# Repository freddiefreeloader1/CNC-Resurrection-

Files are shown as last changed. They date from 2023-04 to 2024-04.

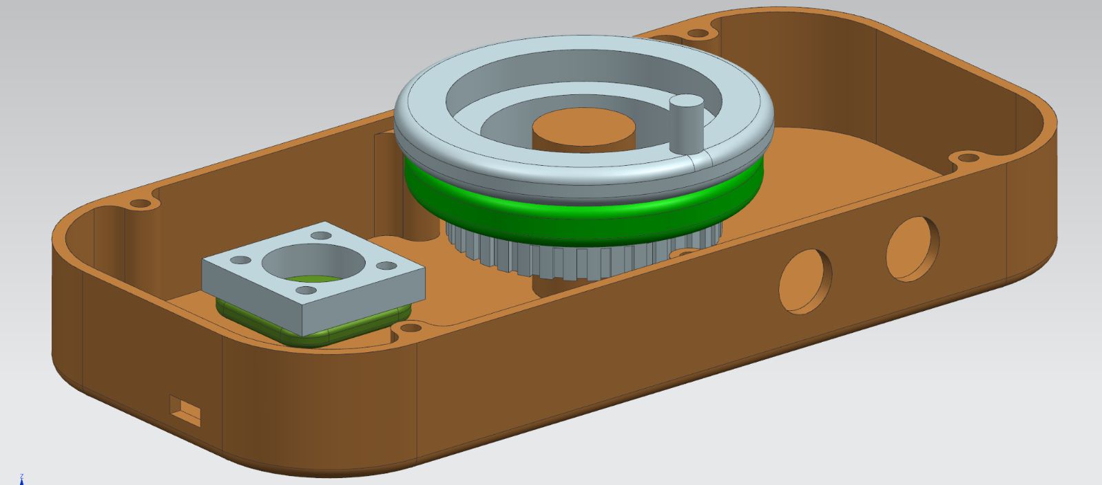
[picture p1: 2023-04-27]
img/RemoteHandWheel_Technical_Drawings/Assembly_3.jpeg

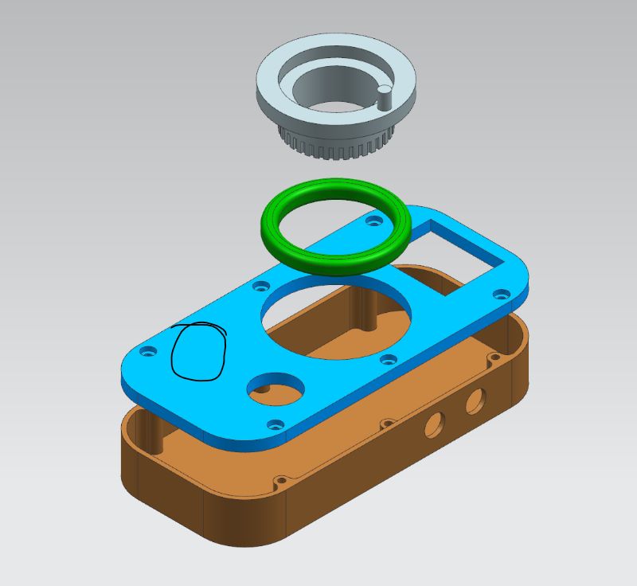
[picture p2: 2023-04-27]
img/RemoteHandWheel_Technical_Drawings/Assembly_2.jpeg

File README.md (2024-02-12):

# CNC-Resurrection
ME462 Term Project 

Main goals:
- Create a generic controller for the out of order CNC machines
- Come up with a ROS2 based universal remote handwheel/controller, mainly for the CNC's, but it should be applicable for other uses as well

Stepper Pairs:
-Pins BH and Pins DF

CNC Milling Machine Specs:

Pitch of the lead screws : 1mm

UGS Parameters:

Step size of axes : 800pulse/mm (Quarter microstepping is enabled)
Max Travel Rate : 150
Do not increase feed rate more than 100mm/min. It staggers motors because motors cannot catch that pulse speed.

REMOTE CONTROLLER DOCUMENTATION:



The Remote Controller project is an innovative and versatile solution designed to provide enhanced control and convenience for various applications. With a range of functional features, this project offers a seamless remote control experience for different devices and systems.

The centerpiece of the Remote Controller project is the GC9A01 round LCD display, which serves as the primary interface. This high-resolution display showcases a user-friendly menu system and subfunctions, allowing users to navigate through different options and select desired actions with ease.

The project currently supports two main subfunctions: CNC and CNC precision. However, the system is highly configurable, enabling the addition of more functions based on individual requirements. This flexibility ensures that the Remote Controller can be adapted to various use cases and applications.

The hardware components of the Remote Controller include a joystick, knob, and three buttons. These components are programmable, allowing users to assign specific functions to perform desired actions. The joystick provides directional control, while the knob allows for precise adjustments. The buttons offer additional input options for quick and convenient operations.

To facilitate seamless communication and integration, all data generated by the joystick, knob, and buttons are transmitted through a socket connection. This connection allows the Remote Controller to interface with other devices or systems, enabling remote control capabilities.

The data received through the socket connection is then sent via a socket-to-ROS2 bridge to a ROS2 (Robot Operating System 2) node. ROS2 provides a robust and flexible framework for managing the control and communication of robotic systems. The Remote Controller project leverages ROS2 to enable efficient data transfer, control, and coordination with other ROS2-enabled devices and modules.

For CNC operations, the Remote Controller project supports GRBL with Arduino. The data received through the socket connection is further forwarded to an Arduino board via serial communication, which interfaces with the GRBL software. This setup allows for precise control over three-axis stepper motors using the knob and joystick inputs, making it an ideal solution for CNC applications.

Powering the Remote Controller is a rechargeable 3.7V battery, providing a portable and convenient power source. The battery can be easily recharged using a micro USB connection through a charge module, ensuring uninterrupted operation. Additionally, a slider switch is incorporated, allowing users to power the controller on and off with ease, preserving battery life when not in use.

The GC9A01 round LCD display provides essential information, including the battery percentage and the position of the knob. This real-time feedback ensures users are aware of the remaining battery power and provides visual cues during operations.

The Remote Controller project offers a comprehensive solution for remote control applications. With its versatile interface, programmable components, seamless integration with ROS2, and support for CNC operations, this project enhances control and convenience across a wide range of devices and systems, providing an exceptional remote control experience.

How To Configure The Remote Controller:

1- There is an opening at the side of the controller that you can connect the Pi Pico W to PC and configure the main.py

2- In main.py, to configure the menu, you can change functions named other2, other3 to suit your needs. You can change the format of the messages sent there. 

3- You also need the to configure the ros2 node. Currently the publisher_member_function only supports the CNC applications. To change it, you need to delete all the code that has serial send in it. You should write your own parsing code for the customized messages you have written in step 2.

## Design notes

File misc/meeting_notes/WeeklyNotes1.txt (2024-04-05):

For the remote:
Joystick - 3 or 4 axis
Wireless Communication
LCD Display
Handwheel - Rotary Encoder Assembly
Functional Buttons

Wireless Communication Concern: Latencies may hinder accurate and precise movement.

CNC pulse generator - handwheel

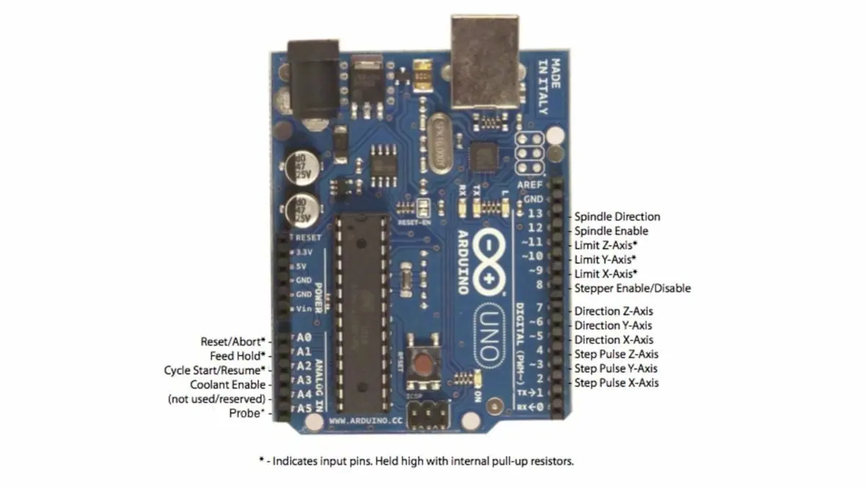
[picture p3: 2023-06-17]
misc/uno-grbl-pinout.webp

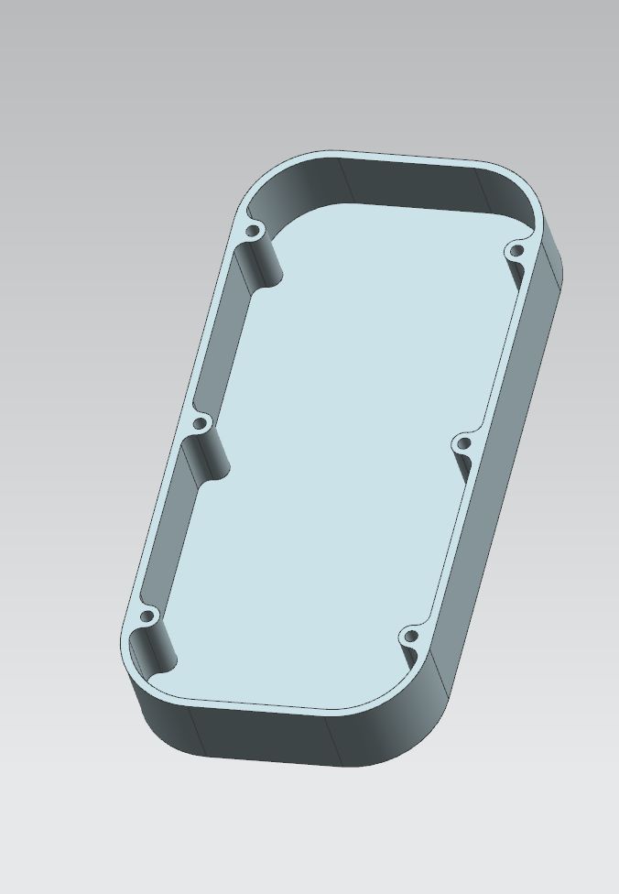
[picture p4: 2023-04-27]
img/RemoteHandWheel_Technical_Drawings/Casing.jpeg

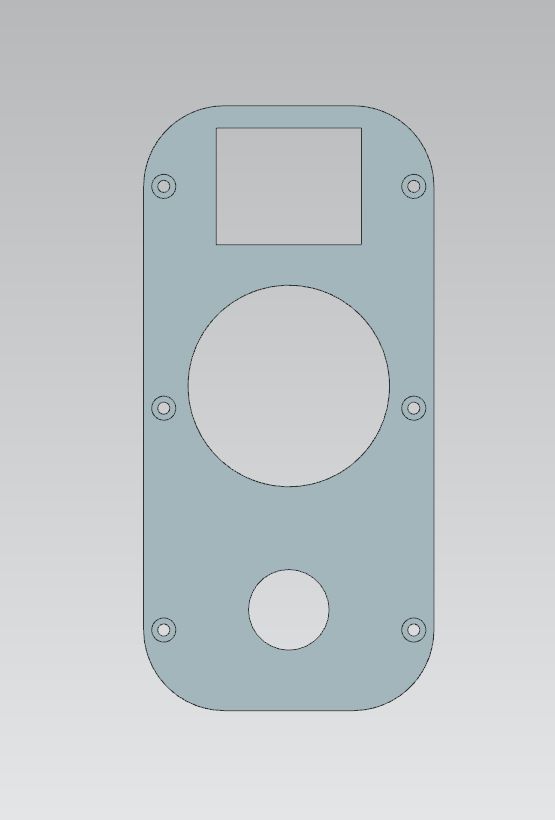
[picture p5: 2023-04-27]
img/RemoteHandWheel_Technical_Drawings/Frame_1.jpeg

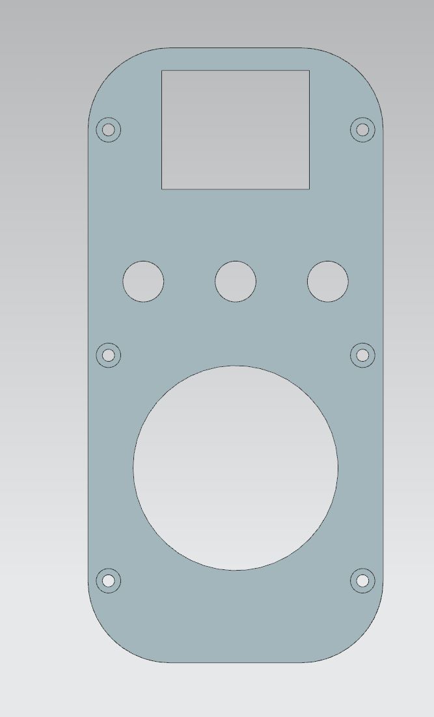
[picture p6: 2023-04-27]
img/RemoteHandWheel_Technical_Drawings/Frame_2.jpeg

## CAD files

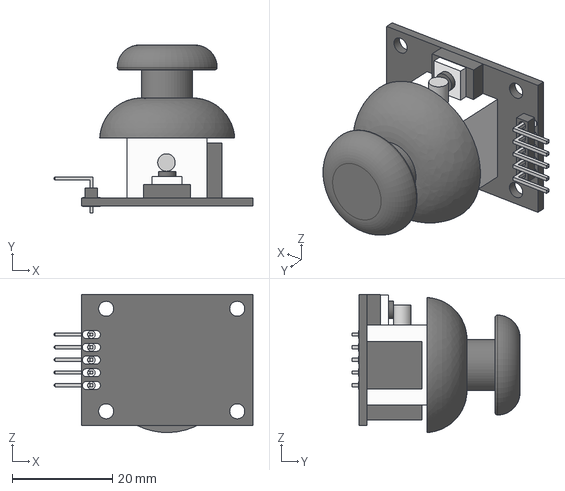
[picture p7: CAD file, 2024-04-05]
misc/TechnicalDrawings_2/joy_stick_2a.step
39.8 x 33.6 x 27.6 mm

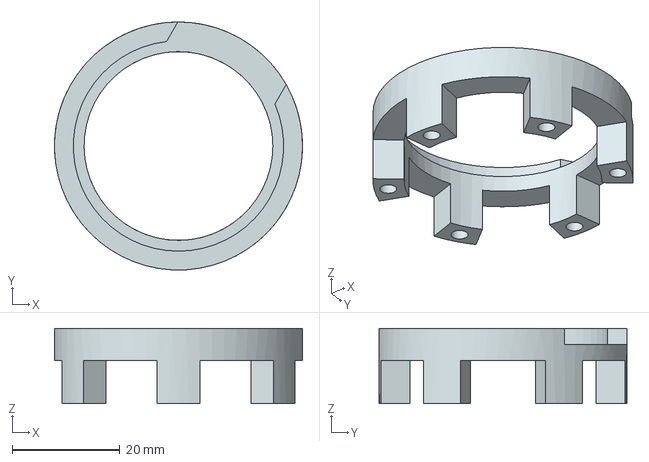
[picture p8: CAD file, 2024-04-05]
Technical Drawings/NEWencoder_housing.stp
46.0 x 46.0 x 14.0 mm

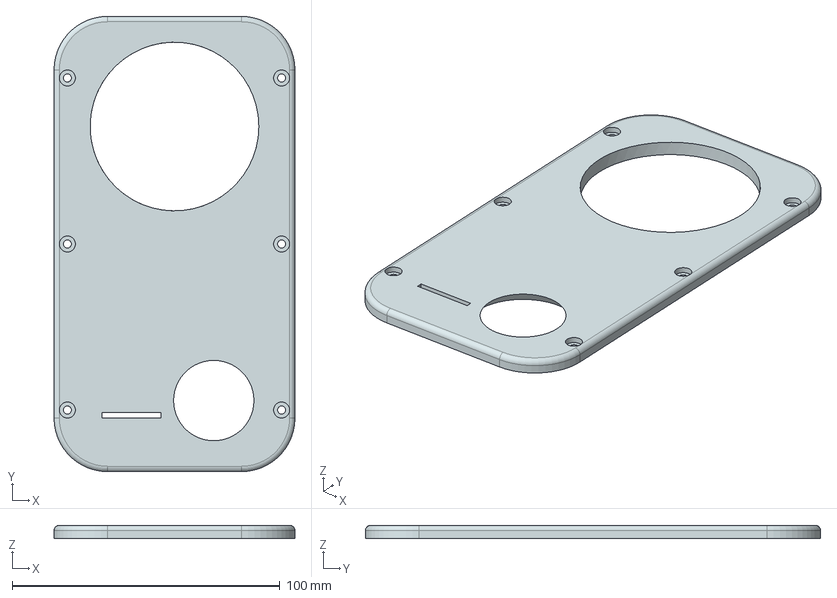
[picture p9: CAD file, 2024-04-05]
Technical Drawings/CAP.stp
90.0 x 170.0 x 5.00 mm

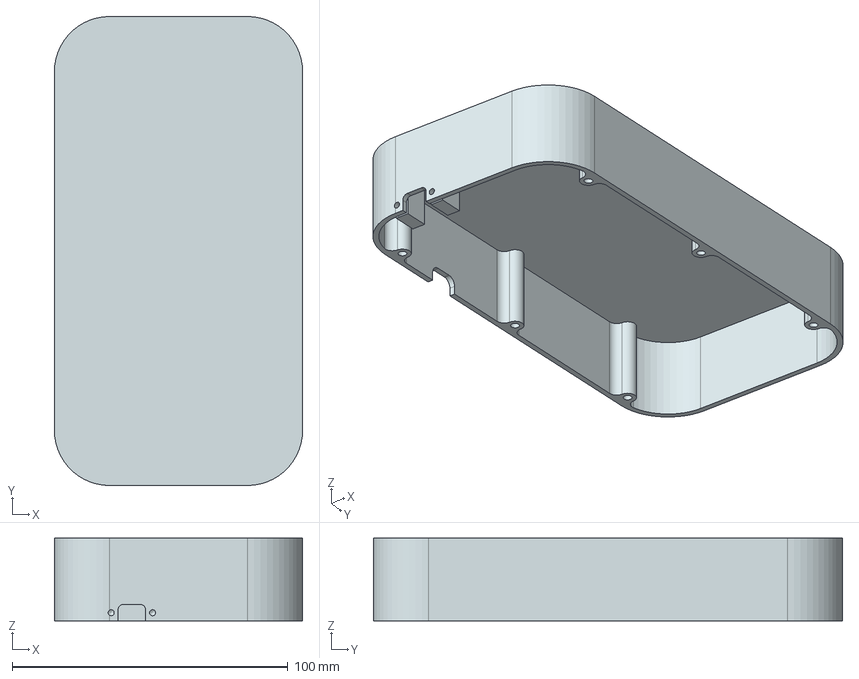
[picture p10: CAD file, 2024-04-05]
Technical Drawings/BACK.stp
90.0 x 170.0 x 30.0 mm

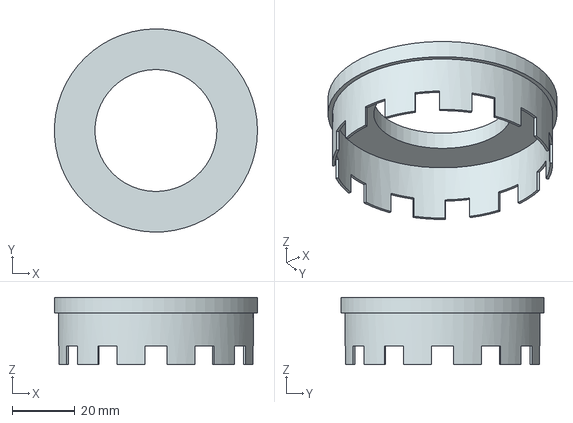
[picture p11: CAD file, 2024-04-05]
Technical Drawings/NEWencod.stp
65.0 x 65.0 x 21.5 mm

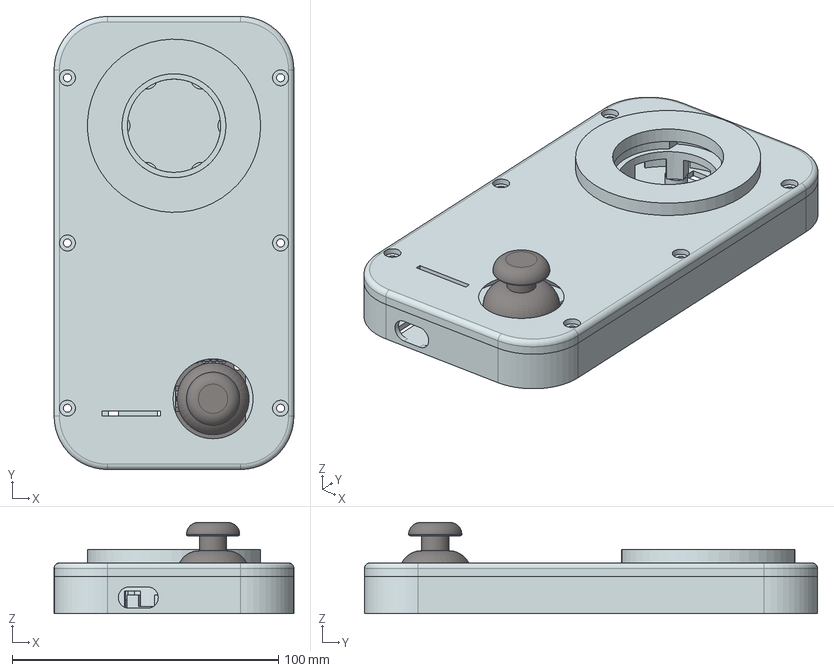
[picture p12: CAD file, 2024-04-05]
Technical Drawings/NEWHANDWHEELBASE.stp
90.0 x 170.0 x 34.2 mm
NEWHANDWHEELBASE_POINTS
NEWHANDWHEELBASE_WF
NEWHANDWHEELBASE_SOLIDS
NEWencoder_housing
NEWencod
CAP
joy_stick_2a_step

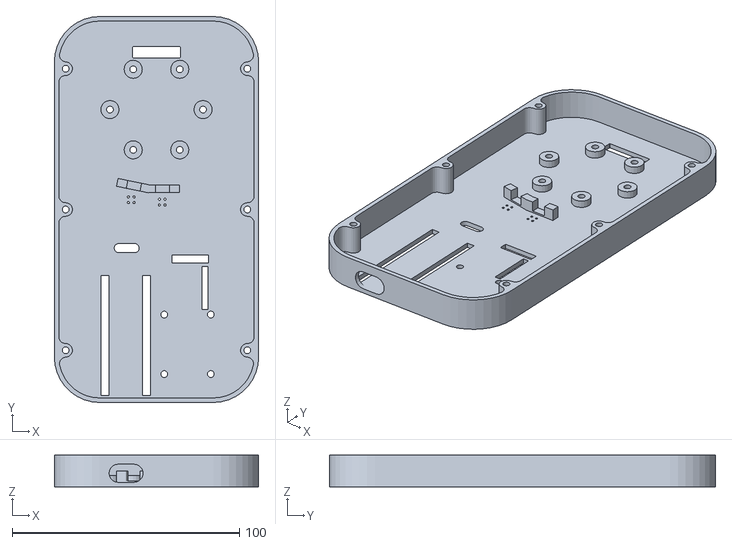
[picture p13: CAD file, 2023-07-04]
Technical Drawings/BASE.stl
90.0 x 170.0 x 14.0

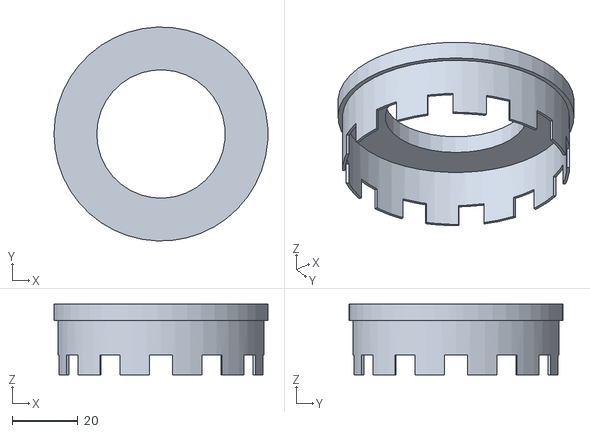
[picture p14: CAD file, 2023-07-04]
Technical Drawings/KNOB.stl
65.0 x 65.0 x 21.5

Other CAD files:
Technical Drawings/LCDHOUSE.stl
Technical Drawings/BACK.prt
Technical Drawings/BACK.stl
Technical Drawings/CAP.prt
Technical Drawings/CAP.stl
Technical Drawings/NEWHANDWHEELBASE.prt
Technical Drawings/NEWencod.prt
Technical Drawings/NEWencoder_housing.prt
img/RemoteHandWheel_Technical_Drawings/61808-Bearing.prt
img/RemoteHandWheel_Technical_Drawings/HW_rotary_encoder.prt
img/RemoteHandWheel_Technical_Drawings/HandWheel_ASM.prt
img/RemoteHandWheel_Technical_Drawings/Handwheel-cap.prt
img/RemoteHandWheel_Technical_Drawings/Handwheel.prt
misc/TechnicalDrawings_2/0508_stp.prt
misc/TechnicalDrawings_2/HandWheel_ASM.prt
misc/TechnicalDrawings_2/Handwheel-cap.prt
misc/TechnicalDrawings_2/Handwheel.prt
misc/TechnicalDrawings_2/encod.prt
misc/TechnicalDrawings_2/encoder_housing.prt
misc/TechnicalDrawings_2/joy_stick_2a_step.prt

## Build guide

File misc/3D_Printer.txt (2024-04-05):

-Yazıcı nozzleı temizlendi bir süre düzgün çalıştı yeniden tıkantı.
-Yazıcı nozzeleı değişti ve yedeklendi.
-Yazıcı filament vermşyordu, dişli kutusu sökülüp temizlendi yeniden takıldı filament veriyor.
-Tabla ayarı bozuktu yeniden yapıldı şu an düzgün çalışıyor.
-Test baskıları düzgün çıktı.
-Tablaya parçalar yağışmadığından düzgün çıkmıyordu asetonla temizlendi, sonrasında da çok yapıştığı için çıkarmak zorlaştı spatula alındı laba koyuldu.

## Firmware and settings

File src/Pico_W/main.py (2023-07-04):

import time
from rotary_irq_rp2 import RotaryIRQ
from machine import Pin, PWM, ADC,  SPI, Timer
from lcd_trial import write_lcd as lcd
import gc9a01 as gc9a01
import vga1_16x16 as font
import NotoSansMono_32 as font2
from math import *
import network
import socket
################################################ LCD
spi = SPI(0, baudrate=60000000, sck=Pin(6), mosi=Pin(3))   # define the lcd pins
tft = gc9a01.GC9A01(
    spi,
    dc=Pin(18, Pin.OUT),
    cs=Pin(20, Pin.OUT),
    reset=Pin(19, Pin.OUT),
    rotation=3)
tft.fill(0)
lcd(tft,"Merhaba",50,100,40000)
################################################# CONNECTION
wlan = network.WLAN(network.STA_IF)
wlan.active(True)
wlan.connect("mechalab_intra" ,"mechastudent")        # enter your own network information
time.sleep(15)                                        # waiting time for wifi connection
print(wlan.isconnected())
if wlan.isconnected() == True:
    tft.fill(0)
    lcd(tft, "wifi: Active", 10,100,15000)
    time.sleep(2)
else:
    lcd(tft, "wifi: Error ", 50,100,15000)
    time.sleep(2)

# # # # # # # # ############################## opening socket
SERVER_IP = '192.168.1.100'                        # learn you global ıp from ifconfig, not the local one! 
PORT = 5151                                        # select the port you want to use, preferably bigger than 1000, choose an unused one 
# Create a socket object
client_socket = socket.socket(socket.AF_INET, socket.SOCK_STREAM)

# Connect to the server socket
try:                                                # try expect makes the code try again if the connection is not succesful
    client_socket.connect((SERVER_IP, PORT))
except OSError as e:
    print(f"Error connecting to server: {e}")
    lcd(tft, "Socket: Error", 10,130,15000)
    

##################################################### buttons
ButtonR = Pin(15,Pin.IN,Pin.PULL_UP)


global flag_R                    # for debouncing 
global counter
global axis

axis = ["X","Y","Z"]                # define the axis list for CNC 
counter = 0                        # define the index counter for the axis list
def callback_R(ButtonR):
    global flag_R
    global counter
    ButtonR.irq(handler = None)

    time.sleep(0.01)
    if flag_R is 0 and ButtonR.value() == 1:
        # print("Interrupt has occured")
        flag_R = 0
        counter = counter + 1
        # print(counter)
        if counter == 3:
            counter = 0


    flag_R = ButtonR.value()
    ButtonR.irq(handler = callback_R)

flag_R = ButtonR.value()

ButtonR.irq(trigger = Pin.IRQ_RISING, handler = callback_R)
##############################################################3
ButtonY = Pin(11,Pin.IN,Pin.PULL_DOWN)


global flag_Y
global counterY
global axisJ

axisJ = ["|X| ","|Y| ","|XY|"]             # define the axis list for the joystick
counterY = 0                               # counter for joystick axis
def callback_Y(ButtonY):
    global flag_Y
    global counterY
    ButtonY.irq(handler = None)

    time.sleep(0.01)
    if flag_Y is 0 and ButtonY.value() == 1:                        # debouncing code
        # print("Interrupt has occured")
        flag_Y = 0
        counterY = counterY + 1
        print(counterY)
        if counterY == 3:
            counterY = 0


    flag_Y = ButtonY.value()
    ButtonY.irq(handler = callback_Y)

flag_Y = ButtonY.value()

ButtonY.irq(trigger = Pin.IRQ_RISING, handler = callback_Y)
############################################################################################## joystick
Buttonjoy = Pin(21,Pin.IN,Pin.PULL_UP)

global counterjoy
global flag_joy                        # debouncing 

counterjoy = 0                        # this is the variable for the selection of menu items, when it is 1 the function is selected in the menu
                    
def callback_joy(Buttonjoy):
    global flag_joy
    global counterjoy
    Buttonjoy.irq(handler = None)

    time.sleep(0.01)
    if flag_joy is 0 and Buttonjoy.value() == 1:
        flag_joy = 0
        counterjoy = 1                # when button is released, make the code select the function
        print(counterjoy)


    flag_joy = Buttonjoy.value()
    Buttonjoy.irq(handler = callback_joy)

flag_joy = Buttonjoy.value()

Buttonjoy.irq(trigger = Pin.IRQ_RISING, handler = callback_joy)

vrx = ADC(Pin(27))                # defining the x and y axis for the joystick, and also define the battery pin for analog read
vry = ADC(Pin(28))
bat = ADC(Pin(26))


def create_array(xval,yval):            # based on some predefined limits, create an direction array for the joystick, e.g. [1, 0] represents positive X direction
    xnum = 0
    ynum = 0
    if xval > 63000:
        xnum = 1
    if yval > 63000:
        ynum = 1
    if xval < 10000:
        xnum = -1
    if yval < 10000:
        ynum = -1
    return [xnum,ynum]
#######################################################################################################
###############################
def interruption_handler(timer):                                
    client_socket.send("HB".encode())


soft_timer = Timer(mode=Timer.PERIODIC, period=5, callback=interruption_handler)            # timer interrupt sends heartbeat at every 5 ms, can configure with changing the period value
################################Buzzer
buzz = PWM(Pin(10))                    # defining buzzer pins
buzz.freq(1000)                        # defining buzzer freq
###############################


r = RotaryIRQ(pin_num_clk=13,            # used an rotary encoder library to use as a quadrate encoder using two QRD's. Define the pins you use for the QRD's in here
              pin_num_dt=22,
              min_val=0,
              max_val=36,
              reverse=False,
              range_mode=RotaryIRQ.RANGE_WRAP)

data = {"joystick":"", "encoder":"","axis":"","axisJ":""}        # create data dictionary for sending it 
val_old = 0                                                    
tft.fill(0)            # clear the lcd
old_val_new = 0
data_k = ""
old_data = {"joystick":"", "encoder":"","axis":"","axisJ":""}        # used for comparing the new data to old data in order to send message at each change in data
lcd(tft, "Socket: Active", 10,130,15000)
time.sleep(1)
tft.fill(0)
client_socket.send("X".encode())                        # send initial axis info to socket 
time.sleep(0.5)
def CNC():
    global counterjoy                                # defining global variables for comparing the old data to new data
    global val_new
    global old_val_new
    global val_old
    global data
    global old_data
    global data_k
    global data_j
    while True:
        batPer = int(bat.read_u16()*100/65535)                    # read battery, joystick, and encoder values
        xval = vrx.read_u16()
        yval = vry.read_u16()
        data_j = str(create_array(xval,yval))                # joystick direction list
        val_new = r.value()                                # encoder value
        lcd(tft,axisJ[counterY],105,70,10000)                    # display all the information on lcd
        lcd(tft,axis[counter],80,70,10000)
        lcd(tft,"%",106,180,15000)
        lcd(tft,"Bat",100,150,30000)
        lcd(tft,str(batPer),120,180,15000)  
        if val_old != val_new:                                    # check if the encoder value changed
               
            buzz.duty_u16(50000)                                # create a sound everytime the encoder value changes
            lcd(tft,".",int(90*cos(old_val_new/5.75))+110,int(90*sin(old_val_new/5.75)+110),0)        # delete the point on the lcd that represents the previous encoder position        

            tft.fill_rect(100, 110, 70,30, 0)
            if (val_new - val_old) < 0:                                            # calculate the encoder step size value. the every step in encoder corresponds to 10 degrees in lcd
                data["encoder"] = -((-(val_new - val_old))%36)
            else:
                data["encoder"] = (val_new - val_old)%36
            client_socket.send(str(data["encoder"]).encode())     # if encoder value changed send the value through socket 
            print(data["encoder"])
            val_old = val_new                                      # assign val_old for comparison
            # print('result =', val_new)
            data_k = str(val_new*10)
            lcd(tft,data_k,100,110,30000)                        # display the angle value on lcd
            lcd(tft,".",int(90*cos(val_new/5.75))+110,int(90*sin(val_new/5.75)+110),4000)            # display a point on the lcd that represents the encoder position as a reference   
            old_val_new = val_new
        buzz.duty_u16(0)
        data["joystick"] = data_j                                            # assign the information to data dictionary 
        data["axis"] = axis[counter]
        data["axisJ"] = axisJ[counterY]
        if data["joystick"] != old_data["joystick"]:                           # compare the old data dict with the new one, if anything changed send the changed information through socket
            client_socket.send(str(data["joystick"]).encode())
        if data["axis"] != old_data["axis"]:
            client_socket.send(str(data["axis"]).encode())
        if data["axisJ"] != old_data["axisJ"]:
            client_socket.send(str(data["axisJ"]).encode())
        
        
        old_data = data.copy()                            # create old_data at each iteration
        if counterjoy == 1:                                # if joystick button is pressed break the loop and return to main menu
            counterjoy = 0
            tft.fill(0)
            break
        time.sleep(0.04)
    
global prec                                             # define precision value for CNC
prec = [0.3, 0.5, 0.7, 1]                                # precision list that can be configured
val_prec = 0                                        
old_val_prec = 0                        # for comparison of the old and new
    
def other1():
    global counterjoy
    global prec
    global val_prec
    global old_val_prec
    while True:
        lcd(tft,"CNC Precision",20,80,15000)                    # display the title
        val_prec = (r.value())%len(prec)                        # val_prec should be in the range 0 and len(prec)
        if val_prec < 0:                                        # if it becomes smaller than 0, return to the last element of the prec list 
            val_prec = len(prec)
        lcd(tft,str(prec[val_prec]),80,120,45000)
        if old_val_prec != val_prec:                            # if anything changed then send the new prec value
            tft.fill_rect(80,120,50,50,0)                        # delete the old prec value on lcd
            client_socket.send(("P" + str(prec[val_prec])).encode())
            print(prec[val_prec])
        if counterjoy == 1:                                # if button joy is pressed, return to main menu
            counterjoy = 0
            tft.fill(0)
            break
        old_val_prec = val_prec
        
def other2():                                                # these functions are configurable for other uses, here you can define your own functions to suit your needs
    global counterjoy    
    while True:
        lcd(tft,"Mini Robot",50,80,15000)
        if counterjoy == 1:
            counterjoy = 0
            tft.fill(0)
            break
def other3():
    global counterjoy   
    while True:
        lcd(tft,"Drone",50,80,15000)
        if counterjoy == 1:
            counterjoy = 0
            tft.fill(0)
            break
        
tft.fill(0)
y = 40
global menu_count
menu_count = 0                                            # keeping track of which menu item we are in 
old_joy = 0
menu = ["CNC","CNC Prec","Mini Robot","Drone"]            # define the menu

while True:
    counterjoy = 0                                        # selection of menu items
    xvalmenu = vrx.read_u16()                
    yvalmenu = vry.read_u16()
    data_joy = str(create_array(xvalmenu,yvalmenu))       # create direction list for joystick for going through the menu
    if data_joy != old_joy:                                # if the list changed, then check what direction
        if data_joy == "[0, 1]":                        # if y direction is upwards increase the menu count
            menu_count += 1
        if data_joy == "[0, -1]":                       # if y direction is downwards decrease the menu count
            menu_count -= 1
        if menu_count < 0:                              # if menu count gets over the lenght of the menu, go to the end or the beginning 
            menu_count = len(menu)
        if menu_count > len(menu):
            menu_count = 0
    for item in menu:
        lcd(tft,item, 50,60 + 20*(menu.index(item)),30000)             # display the menu items
    tft.fill_rect(20,80,20,70,0)
    if menu_count == 0:                                                # display the selector on lcd
        tft.fill_rect(20,80,20,70,0)
        lcd(tft,".",30,60,10000)
    if menu_count == 1:
        tft.fill_rect(20,50,20,70,0)
        lcd(tft,".",30,80,10000)
    if menu_count == 2:
        tft.fill_rect(20,50,20,70,0)
        lcd(tft,".",30,100,10000)
    if menu_count == 3:
        tft.fill_rect(20,50,20,70,0)
        lcd(tft,".",30,120,10000)
    if counterjoy == 1 and menu_count == 0:                        # if the button is pressed and menu count is on specified function, go to that function
        tft.fill(0)
        counterjoy = 0
        CNC()
        tft.fill(0)
    if counterjoy == 1 and menu_count == 1:
        tft.fill(0)
        counterjoy = 0
        other1()
        tft.fill(0)
    if counterjoy == 1 and menu_count == 2:
        tft.fill(0)
        counterjoy = 0
        other2()
        tft.fill(0)
    if counterjoy == 1 and menu_count == 3:
        tft.fill(0)
        counterjoy = 0
        other3()
        tft.fill(0)
        
    old_joy = data_joy                            # to compare the old joystick direction list to the new one    
    time.sleep(0.001)

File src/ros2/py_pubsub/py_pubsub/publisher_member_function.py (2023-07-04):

# import the libraries
import rclpy
from rclpy.node import Node
import socket
from std_msgs.msg import String
import serial
import time 
import re 
# define and inilialize the global variables
global j_val            # joystick direction list
j_val = "[0, 0]"
global hwaxis            # handwheel axis
global stepsize            # defines how many steps should be sent via serial
stepsize = 0
hwaxis = ""
global joyaxis             # defines which axes the joystick should work
joyaxis = ""
global prec                # defines how much should the step motors work after one step
prec = "0.3"

class MinimalPublisher(Node):                    # basic ros2 publisher class that takes the topic name as the input

    def __init__(self, topic_name):
        super().__init__('minimal_publisher')
        self.publisher_ = self.create_publisher(String, topic_name, 10)
        timer_period = 0.5  # seconds
        self.timer = self.create_timer(timer_period, self.timer_callback)
        self.i = 0

    def timer_callback(self):
        #msg = String()
        #msg.data = 'Hello World: %d' % self.i
        ## self.publisher_.publish(msg)
        #self.get_logger().info('Publishing: "%s"' % msg.data)
        #self.i += 1
        pass 

    def publish_data(self, incomedata):
        msg = String()
        msg.data = incomedata
        self.publisher_.publish(msg)
        self.get_logger().info('Publishing: "%s"' % msg.data)
        self.i += 1
def sumdigits(no):                        # the handwheel data sometimes comes as "11-21" when rotated swiftly. This function sums all the digits in this string to find the step size
    if no == 0:
        return 0  
    if "-" in no: 
        return sum(map(int,re.findall(r'(\d|-\d)', no)))        # parsing and summing for strings with negative digits
    else:
        return sum(int(x) for x in no if x.isdigit())            # summing for only positive digit strings

def main(args=None):

    global j_val
    global hwaxis
    global stepsize
    global joyaxis 
    global prec
    com = serial.Serial('/dev/ttyUSB0',baudrate=115200)                # define the serial 
    com.write(str.encode("\r\n\r\n"))                                  # wake up grbl                
   

    serverSocket = socket.socket(socket.AF_INET, socket.SOCK_STREAM);            # opening the socket
    serverSocket.setsockopt(socket.SOL_SOCKET, socket.SO_REUSEADDR, 1)
    serverSocket.bind(("192.168.1.100",5151))                                    # here use your own global ip you found with ifconfig command in linux 

    rclpy.init(args=args)                                                    # init rclpy

    minimal_publisher = MinimalPublisher("CNC")                                # create two publishers, one for the information coming from the remote, and one for the heartbeat
    heart_beat_publisher = MinimalPublisher("heartbeat")

    while(True):                                                # listen for the socket connection

        serverSocket.listen();

        (clientConnected, clientAddress) = serverSocket.accept();

        print("Accepted a connection request from %s:%s"%(clientAddress[0], clientAddress[1]));
    
        break                    # if a connection is received break the loop
    
    while(True):

        dataFromClient = str(clientConnected.recv(1024).decode())                # get the data from the client in string format
        
        if "HB" in dataFromClient:                                        # if there is "HB" string in data, publish to heartbeat topic and get rid of "HB" in the data. 
            heart_beat_publisher.publish_data("HB")
            dataFromClient = dataFromClient.replace("HB","")

        # print(j_val)

        if dataFromClient != "":                                    # if something else comes, also publish "HB" to heartbeat topic, and get rid of it 
            heart_beat_publisher.publish_data("HB")
            if dataFromClient.replace("HB","") != "":
                minimal_publisher.publish_data(dataFromClient.replace("HB",""))   # 

        ############################################## for CNC purposes
        if dataFromClient == "X":                            # here is for initial variables: define the handwheel axis, joystick axis, and the precision according to the data coming from remote
            hwaxis = "X"
        if dataFromClient == "Y":
            hwaxis = "Y"
        if dataFromClient == "Z":
            hwaxis = "Z"
        if "|X|" in dataFromClient:
            joyaxis = "X"
        if "|Y|" in dataFromClient:
            joyaxis = "Y"
        if "|XY" in dataFromClient:
            joyaxis = "XY"
            
        if dataFromClient == "P0.3":
            prec = "0.3"
        if dataFromClient == "P0.5":
            prec = "0.5"
        if dataFromClient == "P0.7":
            prec = "0.7"
        if dataFromClient == "P1":
            prec = "1"
        ############################# HANDWHEEL
        if hwaxis == "X":                                                    # check the handwheel axis
            datahw = dataFromClient.replace("-","")                          # create new string without the - sign, e.g. input string "-1-234", output string is "1234" to check for .isdigit()
            if datahw.isdigit():                                             # check if the data is digit or not 
                stepsize = sumdigits(dataFromClient)                         # calculate the step size 
                print(stepsize)
                if stepsize > 0:
                    for i in range(stepsize):                                # apply the step size
                        com.write(str.encode("G91 G0 X" + prec + "\r\n"))    # apply the precision
                elif stepsize < 0:
                    for i in range(-stepsize):
                        com.write(str.encode("G91 G0 X-" + prec + "\r\n"))

        if hwaxis == "Y":                                                    # same as the X axis 
            datahw = dataFromClient.replace("-","")
            if datahw.isdigit():
                stepsize = sumdigits(dataFromClient)
                print(stepsize)
                if stepsize > 0:
                    for i in range(stepsize):
                        com.write(str.encode("G91 G0 Y" + prec + "\r\n"))
                elif stepsize < 0:
                    for i in range(-stepsize):
                        com.write(str.encode("G91 G0 Y-" + prec + "\r\n"))
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

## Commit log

2023-05-01 Add files via upload
    Schematic of the electronics. Since drivers require loads of pins, another pico is required for screen monitoring. Screen MCU pins are not defined.
2023-05-03 Schematic_v2
    SPI Pins for screen are defined. In addition, 8 Auxiliary pins are also defined for future improvements.
2023-05-09 Update README.md
    added stepper pairs
2023-06-17 Wiring Diagram and Uno GRBL Pinout
    Cnc connection diagram is simplified and drawn as a block diagram. Also added uno grbl pinout for better understanding.
2023-06-21 Add files via upload
    Handwheel size increased , 2 qrd space put in case, joystick holes are done, opend hole for the buttons. It is likely final version
2023-06-22 Add files via upload
    3D printer what we did
2023-06-24 Detailed Connection Diagram of the CNC-Driver Setup
    Detailed connection diagram of the setup. Color Codes of the cables has been specified for forward applications.
2023-06-29 Delete Schematic_v2.pdf
    No need for rpi stepper driver. GRBL and Arduino is used for this project.
2023-06-29 Delete Schematic.pdf
    GRBL in arduino is used
2024-04-05 regulation of files
    [0508_stp.prt, 61808-Bearing.prt, BACK.prt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]
